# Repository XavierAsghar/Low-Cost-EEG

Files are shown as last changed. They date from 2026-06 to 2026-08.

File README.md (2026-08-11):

# Low-Cost-EEG
As part of my Masters Project at University, I have created my own EEG module, with the goal of reducing the cost of EEG technology, and removing barriers to conducting BCI projects/research. 
The module has been verified through the successful detection of Alpha Waves, SSVEPs, and P300s. Additionally the module can also be used to measure other biopotentials, including EMG and ECG. The component cost of the module is £69.07 for 4-Channels, and £99.92 for 8-Channels.

conc 1

### The Hardware
* Up to 8-channels of electrodes can be connected to the input pin headers.
* Texas Instruments ADS1299 EEG Analogue Front-End amplifies and digitises the EEG signal at up to 500 SPS
* The ESP32-S3 then reads the EEG data, and transmits it to a a host computer using Bluetooth Low Energy
* A python script on the host computer unpacks the EEG data, and pushes it to the Lab-Streaming-Layer, for visualisation and recording
* The module is battery powered to ensure patient safety via electrical isolation
* The built in driven right leg helps to cancel common-mode noise

All testing so far has been conducted with standard gold-cup electrodes. For full details of the design and verification of the module, see the Final Report PDF located in the documentation folder. Additionally for complete instructions to use the module, see the User Guide PDF in the same folder. I reccomend using Brainvision LSL Viewer application to view the recorded EEG data in real-time, or the LabRecorder application to record the EEG data.

This repository contains all of production files necessary to create your own module, as well as the source code, and Altium and Inventor Projects needed to modify/continue development of the project. There are several improvements I would like to make to the project before considering it complete, which are discussed in my final report. I have also included the python scripts I used to test for alpha waves, SSVEPs, P300s, and to perform a concealed information test (lie detector).

This project is licensed under the GPL V3 license

### Safety Warning
When connected to a subject, the device must be battery powered, and the USB-C must be disconnected. This is to ensure electrical isolation of the subject from mains.

alpha test

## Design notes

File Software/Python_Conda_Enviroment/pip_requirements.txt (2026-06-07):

bleak==2.1.1
cffi @ file:///D:/bld/cffi_1761202855497/work
contourpy @ file:///C:/miniconda3/conda-bld/contourpy_1763643943275/work
cycler @ file:///C:/Users/task_176606794786808/croot/cycler_1766068049869/work
fonttools @ file:///C:/miniconda3/conda-bld/fonttools_1765445216921/work
joblib @ file:///C:/Users/task_176786740206630/croot/joblib_1767868144069/work
kiwisolver @ file:///C:/miniconda3/conda-bld/kiwisolver_1764159385651/work
matplotlib==3.10.8
mkl-service==2.5.2
mkl_fft @ file:///C:/miniconda3/conda-bld/mkl_fft_1761592917950/work
mkl_random @ file:///C:/miniconda3/conda-bld/mkl_random_1761593166070/work
numpy @ file:///C:/Users/task_177073259650431/croot/numpy_and_numpy_base_1770732703057/work/dist/numpy-2.4.2-cp312-cp312-win_amd64.whl#sha256=695446e7c6dcc91b4f9b187a8af23d4024c9bd8d6a7398d7e5dc9f70c9d701d3
packaging @ file:///C:/miniconda3/conda-bld/packaging_1761049137378/work
pandas @ file:///C:/Users/task_177324583246542/croot/pandas_1773246097950/work
pillow @ file:///D:/bld/pillow_1726075241382/work
ply @ file:///home/conda/feedstock_root/build_artifacts/ply_1733239724146/work
pycparser @ file:///home/conda/feedstock_root/build_artifacts/bld/rattler-build_pycparser_1733195786/work
pygame @ file:///D:/bld/pygame_1727636579027/work
pylsl==1.18.1
pyparsing @ file:///C:/miniconda3/conda-bld/pyparsing_1763973902692/work
PyQt6==6.7.1
PyQt6_sip @ file:///C:/b/abs_28s7k4h_hl/croot/pyqt-split_1740498234166/work/pyqt_sip
python-dateutil @ file:///C:/b/abs_3au_koqnbs/croot/python-dateutil_1716495777160/work
pyxdf @ file:///home/conda/feedstock_root/build_artifacts/pyxdf_1774461975754/work
scikit-learn @ file:///C:/b/abs_45qemhn4lg/croot/scikit-learn_1753427401078/work
scipy @ file:///C:/Users/task_177325432223808/croot/scipy_1773254468529/work/dist/scipy-1.17.1-cp312-cp312-win_amd64.whl#sha256=9e52a540af6dfab956853adc7e87ea66341768053491750b0e193e4baa18feb1
setuptools==80.10.2
sip @ file:///D:/bld/sip_1759437922648/work
six @ file:///C:/b/abs_149wuyuo1o/croot/six_1744271521515/work
sounddevice @ file:///D:/bld/python-sounddevice_1769251727958/work
threadpoolctl @ file:///C:/miniconda3/conda-bld/threadpoolctl_1764361791480/work
tomli @ file:///home/conda/feedstock_root/build_artifacts/bld/rattler-build_tomli_1774492402/work
tornado @ file:///C:/Users/task_176599264648662/croot/tornado_1765992760941/work
typing_extensions==4.15.0
tzdata @ file:///home/task_176829656558347/croot/python-tzdata_1768296637279/work
wheel==0.46.3
winrt-runtime==3.2.1
winrt-Windows.Devices.Bluetooth==3.2.1
winrt-Windows.Devices.Bluetooth.Advertisement==3.2.1
winrt-Windows.Devices.Bluetooth.GenericAttributeProfile==3.2.1
winrt-Windows.Devices.Enumeration==3.2.1
winrt-Windows.Devices.Radios==3.2.1
winrt-Windows.Foundation==3.2.1
winrt-Windows.Foundation.Collections==3.2.1
winrt-Windows.Storage.Streams==3.2.1

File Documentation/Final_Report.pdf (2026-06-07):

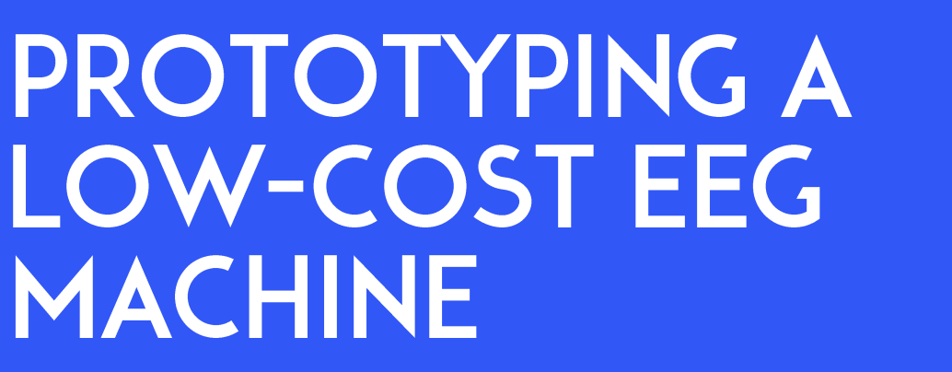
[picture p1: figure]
Prototyping a Low - Cost EEG Machine

Abstract Word Count: 248
Body Word Count: 12,402

Supervisor: Dr Nic Zhang
Assessor: Professor John Taylor

Student Number: 219268967
Integrated Mechanical and Electrical Engineering

Ethical Approval has been Received for this Project

## Xavier Asghar - MEng Final Project Report - 2025/26

Brain-computer interfaces (BCIs) have an expanding range of applications, from assistive technologies for individuals with motor impairments, to autonomous control of mechatronic systems. The increasing availability of commercial EEG devices, from companies such as OpenBCI and Emotiv, has helped make BCI research more accessible outside of clinical and laboratory settings. However these commercial offerings remain prohibitively expensive, often retailing for approximately £1000, and some requiring further subscriptions to access raw data. This high cost has largely excluded EEG technology from educational environments, where it could serve as a platform for student research projects, or as a teaching tool, not just for BCIs, but for signal processing, feature extraction and machine learning.

This report presents the design and validation of a low-cost, open-source EEG module, intended to be easily reproducible. The system utilises the Texas Instruments ADS1299 EEG analogue front end to record high-fidelity EEG signals, alongside an ESP32-S3 microcontroller to wirelessly transmit data to a host computer using Bluetooth Low Energy. A python bridge then pushes the data to the Lab Streaming Layer, enabling real-time visualisation, time-synchronised recording, and integration with established EEG tools. The system records up to 8-channels of 24-bit EEG data at 500 samples per second with no packet loss, and has been validated through the successful detection of alpha waves, SSVEPs, and P300 responses; features that often form the base of BCI systems. With a 4-channel component cost of just £68, the module brings high quality EEG to a cost feasible for educational deployment.

[248 out of a maximum of 250 words]

01 | List of Symbols | 3

# 02 Introduction

| Project Context • Project Aims • Scientific Background | 4
03 | Literature Review Commercial Offerings • Academic Prototypes | 8
04 | System Design Architecture • Firmware • Software • PCB • Mechanical | 10
05 | System Verification EMG • ECG • Alpha Waves • SSVEPs • P300s | 25
06 | Discussions & Conclusions Objectives • Application • Limitations • Improvements • Conclusion | 33
07 | Project Review | 38
08 | Acknowledgements | 40
09 | References | 41
10 | Appendices | 46

# 1. List of Symbols

### 1.1 List of Acronyms

ADC | Analog to Digital Converter
BCI | Brain Computer Interface
BLE | Bluetooth Low Energy
BOM | Bill of Materials
CMRR | Common Mode Rejection Ratio
DRL | Driven Right Leg
ECG | Electrocardiogram
EEG | Electroencephalography
EMG | Electromyography
EMI | Electromagnetic Interference
ENIG | Electroless Nickel Immersion Gold
EP | Evoked Potential
ERP | Event Related Potential
ESD | Electrostatic Discharge
FFT | Fast Fourier Transform
GUI | Graphical User Interface
HASL | Hot Air Solder Levelling
IC | Integrated Circuit
ISR | Interrupt Service Routine
LDO | Low-Dropout Regulator
LSL | Lab Streaming Layer
MUAP | Motor Unit Action Potential
PCB | Printed Circuit Board
RTI | Referred to Input
SNR | Signal to Noise Ratio
SPI | Serial Peripheral Interface
SPS | Samples Per Second
SSVEP | Steady State Visually Evoked Potential
TI | Texas Instruments
VEP | Visually Evoked Potential
XDF | eXtensible Data Format

# 2. Introduction

### 2.1. Project Context

Electroencephalography (EEG) is a non-invasive method of recording spontaneous electrical activity, originating from summed synchronised synaptic activities in populations of cortical neurons in the brain [1, p. 7]. EEG measurements are taken by placing electrodes at multiple locations on the patient’s scalp, and recording the subsequent voltage fluctuations measured at each location. While traditionally used primarily in clinical neurophysiology to monitor and diagnose conditions such as epilepsy, sleep disorders, and brain injuries [2], technological advancements in recent decades have opened up a wide range of new applications involving brain-computer interfaces (BCIs). BCIs use real-time EEG data to control mechanical and electronic devices, with applications including assisting individuals with disabilities and motor impairments, autonomous navigation of mechatronic systems, as well as neurogaming and entertainment [3].

In recent years EEG technology has become more widely available outside of a lab setting, with companies like Emotiv, OpenBCI, Muse, and NeuroSky producing consumer friendly EEG packages that have reduced the barriers to conducting EEG related research [4]. Some of these headsets are shown in Figure 1. However, these devices, which are typically intended to be sold directly to consumers, produce results of varying accuracy, with increased levels of noise [5]. Additionally, a premium is often charged for these devices, as well as for access to proprietary software to view raw EEG data [6], with the more advanced headsets, like OpenBCI’s Ultracortex, or Emotiv’s EPOC X both costing upwards of $1000 [7] [8]. This is in spite of the fact that the core components used to measure biopotentials are not overly expensive, nor are the engineering principles behind these devices overly complex [9].

The high cost of consumer EEG headsets has largely prevented the deployment of EEG technology in educational settings [10] to teach students the fundamentals of brain-computer interfaces. However, by utilising standalone electrodes, rather than relying on fully integrated headset systems, the costs can be brought down to a level feasible for educational deployment. Therefore, this project seeks to develop a low-cost, easily reproducible, and open-source EEG module designed specifically to be used as a teaching tool, as well as for use in future EEG related final year projects.

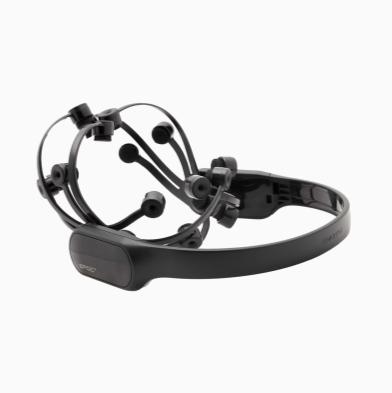
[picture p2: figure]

Figure 1: Commercial EEG offerings, from left to right: OpenBCI Ultracortex [7], Emotiv EPOC X [8], Muse 2 [11]

### 2.2. Project Aims

The primary aim of this project is to use low cost, off the shelf components to design, build, and validate a prototype EEG module. The module must be capable of safely measuring known EEG features, and performing basic data acquisition and signal processing, ensuring the data is easily accessible to the end user. Ultimately the system must be fully documented so it can serve as a reproducible, open-source, educational tool for future brain computer interface research.

It is important to note that several examples of broadly similar low-cost EEG solutions can be found in the literature, as detailed in section 3. However, whilst these papers serve as strong proofs of concept, they fail to provide the reader with sufficient resources to recreate their work, lacking fully realised electrical schematics and code files. The goal of this project is to not just create a tool that can be used within the university, but also can be easily recreated by anyone looking to conduct EEG related research themselves.

To achieve these aims, the project can be broadly divided into four primary objectives, described in Table 1.

Table 1: Project Objectives

Objective 1: Hardware Design and Assembly

Design a low cost printed circuit board (PCB) capable of accurately acquiring EEG measurements from input electrodes, and wirelessly sending the EEG data to an external computer. The PCB must be battery powered, and fully isolated from mains to ensure patient safety.

Objective 2: Software and Firmware Integration

Develop a robust data transmission pipeline, capable of reading data from the analogue front end, wirelessly transmitting said data to a computer, and providing the user with real-time viewing and time-synchronised recording.

Objective 3: System Validation

Test the hardware and software stack to verify its accuracy and safety. This involves conducting human trials to identify known EEG features, including alpha waves, SSVEPs, and P300s

Objective 4: Open-Source Documentation

Produce a comprehensive set of documentation, including a user guide, PCB schematics and Gerber files, commented firmware code and python analysis scripts in order to facilitate future scaling up of the prototype, as well as use and modification in other projects.

### 2.3. Scientific Background

EEG signals are miniscule in magnitude, typically in the order of microvolts [1, p. 26], due to the layers of cerebrospinal fluid, meninges, bone, and skin they must traverse prior to reaching the electrodes on the patient’s scalp [12]. Therefore, recording EEG data necessitates equipment with high levels of precision, as well as adherence to proper procedure when applying the electrodes to a patient. The recorded data originates primarily from the cerebral cortex, the outermost layer of the brain, which contains 14 to 16 billion neurons [13]. This makes the isolation of signals originating from specific neurons impossible, and thus the voltage fluctuation measured at the scalp represents the sum of activities generated from many neural sources surrounding the electrodes [1, p. 8].

Typically, a minimum of three electrodes are required to record EEG data: an active electrode, a reference electrode, and a bias electrode, where the measured voltage is the potential difference between the active, and reference electrode [1, p. 11]. The bias electrode biases the patient such that the common-mode voltage of the active and reference electrode stays within the dynamic range of the EEG circuitry, preventing saturation of the output. More advanced EEG systems also use the bias electrode as part of a noise cancelling feedback loop, called a driven right leg (DRL), where common-mode noise measured from the electrodes, is inverted and fed back into the patient. This helps eliminate the mains-frequency interference that is often present in EEG measurements. [14, p. 68].

The electrodes are most commonly placed on the scalp at some or all of the locations set out by the 10-20 system, shown in Figure 2. This system splits the skull into increments of 10% and 20%, and identifies each location with a letter and number describing the respective brain region and brain side [15]. If using traditional wet electrodes, the skin must be cleaned, and conductive paste must be applied during the electrode application, in order to lower the electrode-skin impedance. On the other hand, dry electrodes can be applied directly to the skin, greatly reducing the required preparation time. However, these electrodes have larger and more unstable electrode-skin impedances, reducing the quality of the recorded data [16].

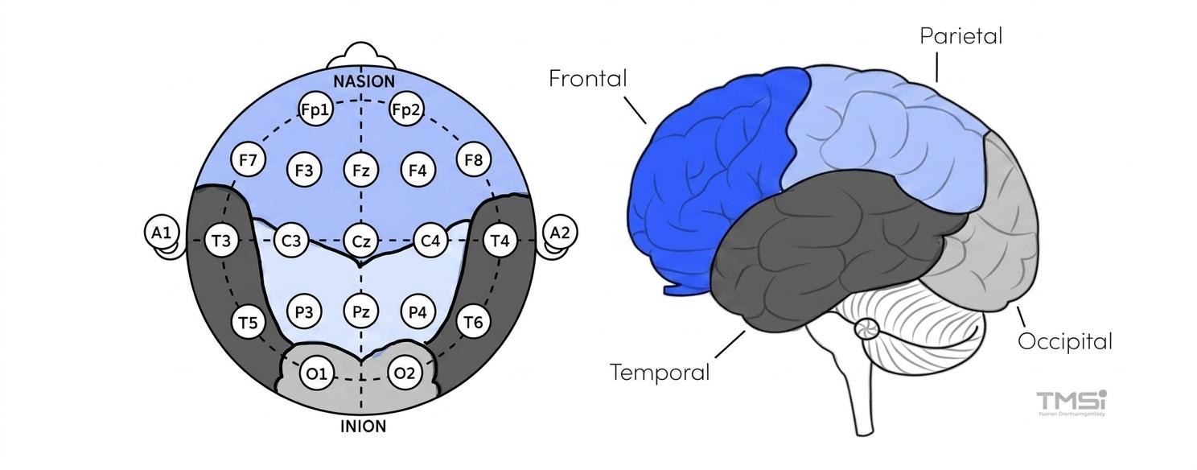
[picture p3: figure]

Figure 2: Diagram showing 10-20 System Electrode Locations [17]

When the electrode input reaches the EEG machine, it is first amplified by an instrumentation amplifier to increase its magnitude and remove common-mode noise. The amplifier should have a common-mode rejection ratio (CMRR) of at least 100 dB to sufficiently remove mains frequency interference [18, p. 1365]. The signal is then bandlimited by an analogue filter, in order to prevent aliasing during the analogue to digital conversion. Finally, an analogue to digital converter (ADC) digitises the EEG signal so it can be processed by a microcontroller [18, p. 977]. EEG headsets typically utilise delta-sigma

ADCs, as their high resolution reduces the need for heavy amplification and filtering, reducing the number of required discrete components [19]. A simple block diagram for an EEG system is shown in Figure 3.

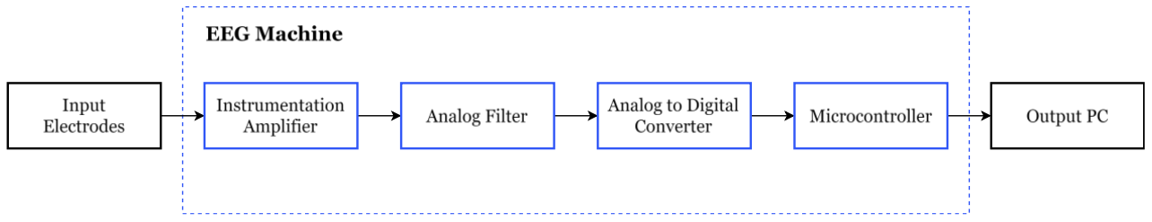
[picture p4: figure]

Figure 3: EEG system block diagram

Once the EEG signal has been digitised by the ADC, it must be transmitted to a computer for signal processing, visualisation, and data analysis. It is important that the data has accurate time synchronisation in order to extract time locked potentials that have been induced by external stimuli. To solve this problem, a framework called The Lab Streaming Layer (LSL) is often used to synchronise data streams from different devices, whilst accounting for network delays, jitters, disconnections and offsets [20]. As well as providing their own software interfaces, companies like OpenBCI and Emotiv both natively support LSL streaming [21], whilst for other platforms, like the Muse, have community created LSL platforms. Once data has been pushed to the Lab Streaming Layer, it can be recorded or visualised by a host of open-source tools, examples of which are given in Appendix I.

EEG machines can be used to record spontaneous EEG activity, as well as event related potentials (ERPs). Spontaneous EEG activity is the background activity of the brain, occurring without any specific external stimulus. It is categorised into frequency bands, each loosely representing different levels of cerebral activity [22]. For example, alpha waves have a frequency of 8 to 13 Hz, and are typically measured from the occipital region of the cortex, from an awake patient with their eyes closed [1, p. 21].

On the other hand, ERPs are time locked EEG responses. These can either be exogenous, commonly referred to as evoked potentials (EPs), which are generated as a result of physical stimulation by a sensory stimulus, or they can be endogenous, being generated by internal cognitive and motor processes [23]. For instance, when a patient observes a light source flickering at a certain frequency, potentials of the same frequency can be measured from the occipital areas of the brain [24]. These are called steady state visually evoked potentials (SSVEPs). On the other hand, possibly the most widely studied endogenous ERP is the P300; a broad positive waveform occurring approximately 300 ms after a patient receives external stimulation [1, p. 62], thought to originate from the brain processing information related to attentional and memory mechanisms [25].

Prior to starting development, a review of existing commercial EEG platforms and relevant academic literature was conducted to gain insight into gaps in the EEG market, to find opportunities for improvement in the current lineup of technology, as well as to inform the design choices made throughout the project.

### 3.1. Commercial EEG Modules

Out of the several commercial EEG headsets on the market, headsets produced by Emotiv have been the most widely used in scientific research [4]. Their EPOC X headset shown in Figure 4.1, provides a highly integrated, user-friendly 14-channel system, albeit with varying levels of reported accuracy [5] [26] [27]. However, its restrictive pricing model limits its ability to be used in an educational environment. The EPOC X is currently priced at $999 [8], while the 32-channel Mind Flex 2 starts at $1,899 [28]. Moreover, accessing and exporting raw EEG data requires a subscription to their EmotivPRO software, costing $149 per month for a standard tier subscription [6].

In comparison, OpenBCI produce a fully open-source EEG platform, which gives the user full control over the entire EEG process. Their Cyton PCB module, shown in Figure 4.2, lets the user choose the number, type and location of electrodes, as well as whether the data is viewed on the OpenBCI GUI, or pushed straight to the Lab Streaming Layer. Whilst providing a platform better suited for research, and of comparable quality to clinical EEG machines [29], the hardware costs remain high. The Cyton board alone costs £933, whilst the complete Ultracortex, which integrates the Cyton board with their own 3D-printed headset and dry-electrodes, costs £2,255 [30].

More recently the Cerelog ESP-EEG board, shown in Figure 4.3, was introduced to the market [31], also with the intention of lowering the cost of BCI technology. Similarly to the OpenBCI Cyton, the Cerelog module is built around the Texas Instruments (TI) ADS1299 [32], which integrates EEG amplification, analogue to digital conversion, as well as other EEG specific features, to provide a fully integrated EEG analogue front end [14]. The Cerelog platform also has strong software integration, allowing the user to view their data on a fork of the OpenBCI GUI, or use the popular Brainflow EEG library to access raw EEG data. However, the system does not yet support wireless data transfer, relying instead on a USB connection. As well as restricting patient mobility, this presents a danger to the user if the host computer is connected to mains, as there will be no electrical isolation of the patient. Furthermore, the hardware remains relatively expensive, with a base price of $650.

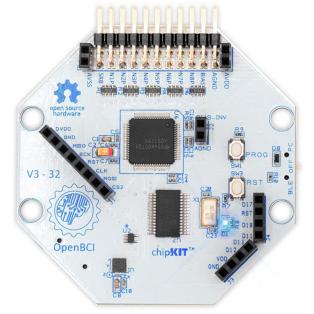
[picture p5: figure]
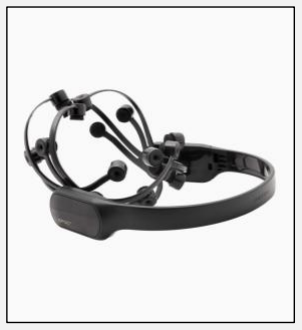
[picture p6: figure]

Figure 4: From left to right: Emotiv EPOC X [8], OpenBCI Cyton [33], Cerelog ESP-EEG [31]

### 3.2. Academic Low-Cost Prototypes

As well as commercial offerings, there are also several studies that document the production of low-cost EEG platforms.

In 2013, Pennsylvania State University researchers also identified a need for low-cost EEG modules to use as an educational tool [9]. They observed difficulties in getting student buy-in for their BCI classes, as the high hardware cost meant students had limited access to EEG equipment. An older, electrocardiogram (ECG) specific version of the aforementioned TI chip; the ADS1298, was paired with a TI MSP430 series
microcontroller, known for its exceptionally low power
consumption [34], to create an EEG acquisition module
with a component cost of under $100, shown in Figure
5. They then validated their system through the detection of alpha waves and a visually evoked p300 response. Overall, a strong EEG platform has been presented, with minor improvements being wireless
data transfer, battery power, and stronger software
integration.

In 2017 Nguyen et al. [35] documented an ADS1299 based EEG system, this time using an STM32F4 microcontroller, which they validated using alpha wave detection and Electrooculography (EOG) eye tracking tasks. To overcome the mobility limitations of previous wired systems, Bluetooth data transmission was implemented using a HC – 05 Bluetooth module. However the authors admit the system was susceptible to high levels of noise, possibly due to not utilising the ADS1299’s driven right leg functionality, highlighting the importance of using the patient bias as an active ground to cancel common mode noise.

More recently, Gao (2023) [36] developed another ADS1299 STM32 EEG system, with the intent of creating an EEG module possessing the accuracy of large laboratory EEG setups, but on a much smaller scale. Once again a separate
bluetooth module, the NRF52832, was used to send
data to a computer. The system, shown in Figure 6, was
verified by using fourier analysis to test for SSVEPs across multiple stimulus frequencies. This paper goes further than the previous examples in documenting their work, with snapshots of electrical schematics, however it is still far from being easily reproducible. Additionally the system is not integrated with any
established EEG software frameworks, like brainflow or
LSL.

In conclusion, the ADS1299 has established itself as the analog front end of choice in low-cost, portable EEG modules, both in commercial products and in academic research. Additionally, alpha wave, P300, and SSVEP detection methods have repeatedly been used as methods of verifying the accuracy of proposed systems. Overall strong proofs of concept for small scale, low cost ADS1299 based EEG systems have been provided. However, the work done in these papers is not easily reproducible, and despite the decreasing costs of EEG hardware, users and researchers are still left without a truly low-cost solution.

Figure 6: Gao (2023) EEG Module

Figure 5: Pennsylvania State University EEG Module

# 4. System Design

### 4.1. Component Selection & System Architecture

4.1.1. ADC Selection

The first stage of the design process involved selecting a suitable analogue to digital converter, as this component dictates the overall system architecture.

As evidenced by the literature review, the ADS1299 is the standard for low-cost EEG modules. This is primarily due to its exceptionally low input referred noise, high CMRR, and large input impedance [14]. The ADS1299 also comes equipped with several EEG specific features, including lead-off detection to identify poor electrode-skin contact, built in driven right leg circuitry for common mode noise cancelation, and an internal multiplexer which allows for the routing of the reference electrode to the negative pin of each differential input. However, this high level of integration carries a financial premium, as the ADS1299 currently retails for £64.57 from Mouser Electronics. To adhere to the low-cost objective of the project, cheaper alternatives were evaluated.

One alternative approach is to use an ECG analogue front end, similarly to how the ADS1298 was utilised at Pennsylvania University. However, since these ICs are intended for ECG applications, where signal amplitudes are orders of magnitude larger [37], they offer comparatively poor noise performance. Another option is to use a non-application specific ADC, such as the Analog Devices AD7779, that also features 8 simultaneously sampled 24-bit channels.

Table 2 compares the performance metrics of these ADCs, specifically evaluating their theoretical capability to measure a 10 µVpp P300 ERP [38]. Referred to input (RTI) noise levels are assuming a maximum PGA gain and minimum data rate, and thus represent a lower bound. The RTI least significant bit (LSB) size has been calculated with Equation 1:

LSBRTI =

2 ∙ (

Vref
PGA Gain)

2

Bits | (Equation 1)

Table 2: ADC performance comparison when measuring a 10 µVpp P300 [14], [39], [40], [41]

IC | RTI Noise (µVpp) | P300 Noise Contamination (%) | PGA Gain | RTI LSB (µV) | P300 Quantisation Steps | Mouser Cost
ADS1299 | 0.98 | 9.8 | 24 | 0.022 | 447.39 | £64.57
ADS1298 | 2.7 | 27 | 12 | 0.040 | 251.66 | £34.39
AD7779 | 2.28 | 22.8 | 8 | 0.037 | 268.44 | £14.49
AD8422* | 0.15 | 1.5 | | | | £5.60
*Note: The AD8422 is an instrumentation amplifier, not an ADC.

The ADS1299 has the lowest RTI noise, as well as the lowest RTI LSB size, enabling precise and low noise acquisition of a P300 wave. In contrast, using the ADS1298 or AD7779 would result in a P300 signal that is contaminated with approximately 25% noise, and recorded at almost half the effective resolution.

The lower performance metrics of the cheaper ADCs could be compensated for by placing an instrumentation amplifier stage prior to the ADC, for instance the AD8422, which has an ultra-low RTI noise of 0.15 µVpp. However, despite outperforming the ADS1299 in terms of noise performance, this would add increased complexity and cost, since each channel would require a dedicated instrumentation amplifier.

Consequently, the ADS1299 was selected. Its low RTI noise and high PGA gain ensure high fidelity signal acquisition, while its EEG specific features minimise circuit complexity and reduce the need for other components. Moreover, in some cases the increased cost can be mitigated by using the 6-channel, or 4-channel variants, which are priced at £51.52 and £32.75 respectively.

4.1.2. Microcontroller Selection

Following the selection of the analogue front end, a suitable microcontroller was required to manage SPI (Serial Peripheral Interface) communication with the ADS1299, and send the EEG data to a host computer.

Project Objective 2 states that data transmission from the EEG module to a host computer must be completely wireless. This is primarily to ensure electrical isolation between the user and mains power; however, it also removes the physical tether to the host device, granting the user full mobility. Consequently, the search was restricted to microcontrollers with Bluetooth integration. Utilising an external Bluetooth module would add unnecessary complexity to the project by way of introducing another serial bridge to the data path, not to mention increasing the bill of materials (BOM), and consuming additional PCB real estate.

This primary constraint was used to narrow down the field to three primary candidates, summarised in Table 3. The STM32 architecture was considered due to its high performance, low power consumption and robust ecosystem [42]. While the STM32F4 range of microcontrollers used by Nguyen et al. [35] and Gao [36] do not come with Bluetooth, STMicroelectronics have a capable dual core Bluetooth offering in the STM32WB55. Alternatively, one of the most widely used microcontrollers for Bluetooth Low Energy (BLE) applications is the Nordic Semiconductor nRF52840, due to its low power consumption and an extremely stable Bluetooth stack. In fact Nordic sells approximately 40% of all BLE chips in industry [43].

Table 3: Bluetooth microcontroller comparison

Micro | Cores | Clock Speed | Max RAM | Max Flash | Unit Cost
STM32WB55 | 1x ARM Cortex-M4 1x ARM Cortex-M0+ | Core 1: 64 MHz Core 2: 32 MHz | 256 KB | 1 MB | £6.77
nRF52840 | ARM Cortex-M4 | 64 MHz | 256 KB | 1 MB | £4.85
ESP32-S3 | 2x Xtensa LX7 | 240 MHz | 512 KB | 16 MB (external) | £1.39

Despite the popular STMicroelectronics and Nordic offerings, the Espressif ESP32-S3 was chosen for this project. As evidenced by Table 3, the ESP32-S3 outperforms the STM32WB55 and nRF52840 in terms of computational power, possessing two 240 MHz cores, and double the amount of SRAM. This dual core architecture allows for data reading, and data sending to each be localised to an individual core, in a way that would not be possible on the nRF52840.

From a hardware design perspective, the ESP32-S3 is widely available as a pre-certified, shielded module: the ESP32-S3-Wroom-1, containing an integrated PCB antenna, crystal, and external flash memory. This, combined with native USB support, once again removes unnecessary complexity from the project, for example RF layout and USB to UART conversion. Additionally, the module form factor is priced very reasonably, with costs starting at £3.80, and development boards costing around £10.

4.1.3. Electrode Selection

While the EEG module is intended to be electrode agnostic, a set of electrodes needed to be selected for system validation. Electrodes generally differ across two primary metrics: active vs passive, and wet vs dry.

Active electrodes, shown in Figure 7.1, amplify the EEG signal directly at the electrode, preventing undesired electrical noise, particularly at mains frequency, from coupling into the lead wires and contaminating the signal. These would require dedicated power routed from the PCB, and are typically more expensive, and more difficult to source than their passive counterparts, that simply transmit the signal to the EEG machine for amplification. Furthermore, research indicates that in high quality, laboratory conditions, specifically with low electrode-skin impedances, passive electrodes provided a cleaner baseline signal [44].

Figure 7: EEG electrode types: active electrodes (left) [45], dry electrodes (middle) [46], and passive gold cup electrodes (right) [47].

Regarding electrode application, wet electrodes are the clinical standard. These require the use of a conductive paste, gel or saline solution during the application process, which will dry out after a certain amount of time. Moreover, the skin needs to be prepared before application to reduce the electrode skin impedance, typically by applying an abrasive gel like Nuprep or using alcohol wipes and mechanical abrasion. On the other hand, dry electrodes, as shown in Figure 7.2, can be applied directly to the scalp without the need for preparation. While convenient, this comes at a cost to performance, as they were found to produce significantly larger noise levels compared to both active and passive wet electrodes when conducting a P300 oddball test [48].

For this project, passive wet gold cup electrodes were chosen, primarily due to their low cost, wide availability, and reliable signal acquisition. While the ease of use of dry electrodes is well suited to an educational environment, establishing clean EEG data was prioritised for the initial hardware tests. However, in the future it may be worthwhile testing the system with dry electrodes, to assess their viability. A total of eight electrodes were sourced from Chinese app Pinduoduo, amounting to £15.

4.1.4. Overall System Architecture

Following the selection of the primary hardware components, a complete system architecture was defined. Figure 8 illustrates this architecture, mapping out the signal flow from the brain to the final GUI.

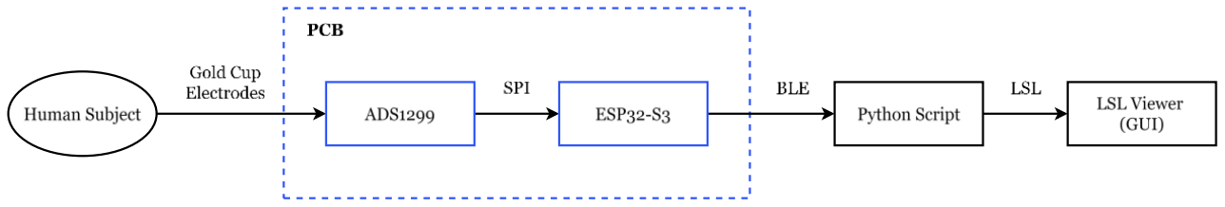
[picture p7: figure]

Figure 8: System architecture flow chart

EEG data is first acquired from the scalp using gold cup electrodes. This necessitates skin preparation as well as the use of conductive paste during the application process. The ADS1299 then amplifies the signal, removing common mode noise, before digitising the data from a maximum of 8 channels.

The digitised data is subsequently transmitted via SPI to the ESP32-S3 microcontroller, where it is batched into packets to be transmitted using the BLE protocol, with the ESP32-S3 acting as a GATT (Generic ATTribute Profile) server. This ensures that electrical isolation is maintained between the user and mains.

Finally, at the host computer, a python script will act as the GATT client, subscribing to notifications from the GATT server. The script unpacks the incoming byte arrays, including checking for lost packets, before pushing the data to an LSL outlet. Utilising the LSL framework allows the data to be viewed in real time using tools such as BrainVision LSL Viewer or OpenViBE, and recorded using Lab Recorder. Additionally, it allows users to synchronise the recorded data with external stimuli, through the use of LSL marker streams.

### 4.2. Bench Prototyping and Firmware Design

4.2.1. Initial Prototyping

Once component selection had been completed, the development boards for the ADS1299 (ADS1299EEGFE-PDK) and ESP32-S3-Wroom-1 (S3-DevKitC-1) were purchased to conduct initial tests.

To establish a performance baseline prior to introducing custom firmware, the ADS1299 was first evaluated using the included MMB0 motherboard. This board interfaces between the ADS1299 and the Texas Instruments evaluation software, allowing for visualisation and Fast Fourier Transform of channel inputs, and direct manipulation of the internal control registers.

Initial validation was conducted by connecting the positive channel and reference inputs of the development board to a signal generator. Figure 9.1 shows the results of a 1 mVpp input sine wave, while Figure 9.2 shows the respective frequency domain FFT. Further validation was performed by routing the ADS1299’s internally generated 3.6 mVpp test signal to channel 1, the results of which are shown in Figure 9.3.

Figure 9: ADS1299 EVM tests: 1 mVpp input (left), 1 mVpp FFT (middle), internally generated square wave (right)

Further bench tests verified the DRL circuitry, PGA configuration and bipolar supply operation. In addition, the intrinsic noise floor was recorded at 2 µVpp, confirming the device was operating as set out in the datasheet.

This initial testing phase was useful for understanding functionality and register setup of the ADS1299. Once completed, the analogue front-end board was separated from the MMB0 motherboard, and jumper wired to the S3-DevKitC-1, as shown in Figure 10. Table 4 lists the wire connections between the two boards.

Table 4: ADS1299 ESP32 communication pins

ESP32 Pin | ADS1299 Pin
8 | RESET
9 | DRDY
10 | CS
11 | DIN (MOSI)
12 | SCK
13 | DOUT (MISO)
18 | START

Figure 10: Development Setup

4.2.2. ADS1299 Communication Library

The next stage of development involved the creation of a library to interface the ESP32-S3 with the ADS1299, which communicates using SPI. Aside from the four main SPI pins; DIN, DOUT, SCK, and CS, the ADS1299 also has several dedicated communication pins including RESET, START, PWDN and DRDY.

During standard operation the ADS1299 is placed in the Read Data Continuous (RDATAC) mode. When the START pin is low, and on the falling edge of the DRDY pin, DOUT releases 216 bits of data, comprising of 24 status bits, followed by eight 24-bit channel readings. In order to configure the device, including reading from and writing to internal registers, the data stream must be halted using the Stop Read Data Continuous Command (SDATAC), releasing the SPI buses.

An open-source communication library for the ADS1299 already existed, having been developed by Conor Russomanno, one of the founders of OpenBCI [49]. However, this library was specifically designed for 8-bit AVR microcontrollers, for instance the ATmega328P found on the Arduino Uno R3, as it manipulates the AVR specific SPI control registers directly. This renders the library incompatible with the 32-bit Xtensa processors found on the ESP32-S3. Furthermore, the original library was designed to act as a pass through, printing all received data straight to the serial port to be processed by a host PC, while the architecture used in this project transmits data over Bluetooth instead.

To resolve these incompatibilities, Russomanno’s library was modified to use the standard Arduino SPI library, making it compatible with any microcontroller using the Arduino framework. Additionally, the following changes were implemented:

1. Rather than pushing recorded bits straight to the serial monitor, they are sign extended into 32-bit integer longs, and which are then returned as outputs.
2. The updateData function responsible for reading data from the ADS1299 was changed with the intention of being called by an interrupt when the DRDY pin has been pulled low, rather than being polled from the main loop.
3. A new updateDataPacket function was added, which skips sign extension and reading the data into a long, instead dropping the channel data directly into a byte array, to be sent over Bluetooth.
4. Correct power up sequencing was added to the setup function, removing the need for the user to manually follow the power-up sequence set out by the datasheet before sending instructions.

The complete source code for the revised ADS1299 communication library can be found in Appendix B.

4.2.3. ESP32-S3 Firmware

With the ADS1299 communication library complete, the ESP32-S3 firmware was developed with Platformio, using the Espressif’s Arduino Core. The firmware has two primary objectives: to accurately read data from the ADS1299 on the falling edge of the DRDY pin, and to transmit data to the host computer using Bluetooth Low Energy, with high-throughput and no data loss. Combining these two objectives onto a single execution thread risks one task blocking the other, particularly due to the precise timing requirements of each task. Even at the lowest data rate, the ADS1299 is sending a 216-bit sample every 4 milliseconds, that needs to be read, decoded, packaged and transmitted. To solve this problem, the dual core architecture of the ESP32-S3 was utilised, with one core in charge of reading data, and the other responsible for transmitting it. The overall structure of the firmware can be seen in Figure 11.

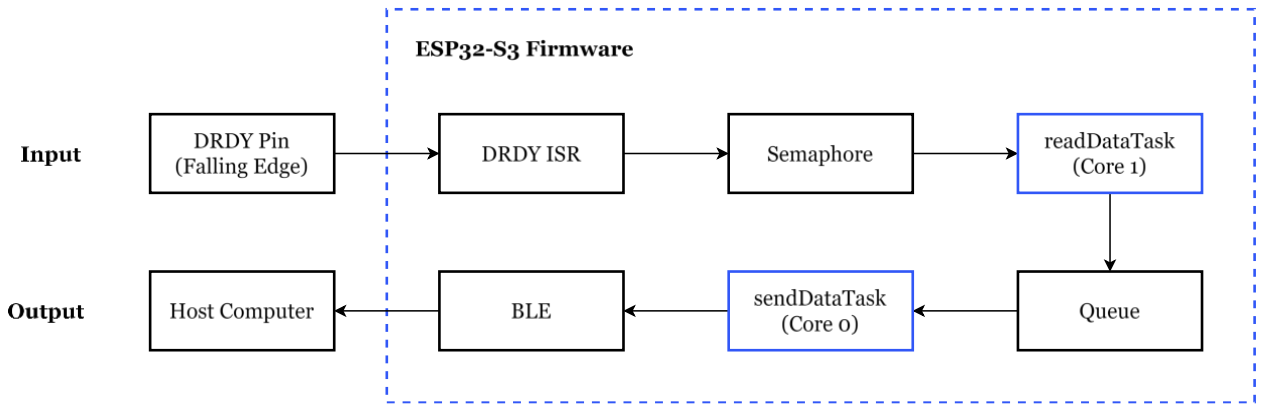
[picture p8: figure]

Figure 11: ESP32-S3 firmware architecture diagram, showing dual core pipeline.

When the DRDY pin is pulled low, indicating that there is a new sample available, an interrupt service routine (ISR) is called, which gives to a binary semaphore, and immediately yields to a higher priority task, if one is waiting. The ISR, shown in Listing 1, has been kept minimal, to ensure that other DRDY interrupts are not delayed, reducing the risk of sample loss.

Listing 1: DRDY ISR function

void IRAM_ATTR dataReadyISR() {
BaseType_t xHigherPriorityTaskWoken = pdFALSE; xSemaphoreGiveFromISR(drdySemaphore, &xHigherPriorityTaskWoken); if (xHigherPriorityTaskWoken) {
portYIELD_FROM_ISR();
}
}

The task of reading data from the ADS1299 is pinned to core 1 of the ESP32-S3, at a priority level of 3. This task, shown in Listing 2, spends most of its time blocked, waiting for the semaphore to be released. When the semaphore is given by the ISR, the task wakes up and increments a sample counter, which is put in byte 0 of a 28-byte packet. The updateDataPacket function is then called to fill the remaining 27 bytes with EEG data read from the ADS1299, and the completed packet is pushed to a queue, to be sent to the secondary task running on the other core. The sample counter can be used by the host to determine if any samples have been lost.

Listing 2: Read data task (core 1)

for(;;) {

if (xSemaphoreTake(drdySemaphore, portMAX_DELAY) == pdTRUE) {
dataPacket[0] = sampleCounter++; | // 1. Assign the Sample Counter
ADS.updateDataPacket(dataPacket); | // 2. Read the SPI Data
xQueueSend(packetQueue, dataPacket, 0); // 3. Send to the Bluetooth Core }
}

The task of sending data to the host computer runs on Core 0 at a priority level of 1, alongside the BLE stack, and is shown in Listing 3. This core is blocked until a sample becomes available in the queue, at which point it is added to a 224-byte batch buffer. Once eight packets have been received, and the buffer is full, the batch is transmitted as a single GATT notification. Batching the data is necessary as BLE notifications carry overheads, and thus sending each 28-byte sample individually would consume a greater amount of radio time. In particular a factor of 8 was chosen as it fits nicely within BLE’s 251-byte extended data channel payload [50], maximising the data sent with each notification.

Listing 3: Send data task (core 0)

// Wait for a single 28-byte packet from Core 1
if (xQueueReceive(packetQueue, &singlePacket, portMAX_DELAY) == pdPASS) { // Copy the 28 bytes the 224-byte batch buffer memcpy(&batchBuffer[batchCount * 28], singlePacket, 28);
batchCount++;
// After 8 packets, send the full 224-byte batch
if (batchCount == 8) {
pCharacteristic->setValue(batchBuffer, 224); pCharacteristic->notify();
batchCount = 0; // Reset the batch count
}
}

The sample queue has a depth of 256, providing approximately half a second of buffering when the ADS1299 is running at 500 SPS, absorbing any short term BLE delays. The system is capable of transmitting data at 500 SPS with no data loss (equivalent to 14 kB/s), however at 1000 SPS packets start to be dropped due to limitations regarding the windows connection interval. A possible mitigation would have been to use Bluetooth Classic rather than BLE, which provides a continuous steam of data, but is only supported on the original ESP32, and not the newer ESP32-S3 selected for this project. Nevertheless, 500 SPS, which results in a Nyquist frequency of 250 Hz, is more than enough for most EEG applications, where the data is often filtered to cutoff frequencies far below this value.

The code is also written such that there is an initial connection phase, where the ADS1299’s DC lead off circuitry is active. This is where a small excitation current is injected to each of the active electrodes, and a comparator threshold detects whether the resulting voltage indicates an open circuit. Once the connections are verified, the user can press the boot button to disable the lead-off circuitry, which would have otherwise contaminated the EEG measurements.

The completed firmware uses 900 KB of flash, and 140 KB of internal SRAM, leaving 7.1 MB and 248 KB respectively free for future development. The complete source code for the ESP32-S3 can be found in Appendix C.

### 4.3. Host Software Design

4.3.1. Python BLE Client and LSL Bridge

The host software is responsible for receiving and decoding the EEG data stream sent by the ESP32-S3, before pushing the data to the Lab Streaming Layer for visualisation and recording. Python was chosen as the implementation language due to the availability of mature libraries for relevant tasks: Bleak for receiving BLE data, Pylsl for pushing data to the LSL, and Asyncio to run and manage an event loop.

Python’s Asyncio framework was used to manage the operation of the host script. Asyncio implements cooperative concurrency on a single thread, which is controlled by a central event loop, scheduling tasks that voluntarily yield control at explicit ‘await’ points. Unlike multi-threading, this model guarantees that no task is interrupted mid execution, eliminating the need for locking of variables to prevent race conditions. The Bleak library by default runs on top of Asyncio, as BLE communications are inherently I/O bound, and the system needs to be able to read the notification data without blocking other sections of the code. The script is organised into three concurrent tasks running on the event loop, and the overall structure can be seen in Figure 12.

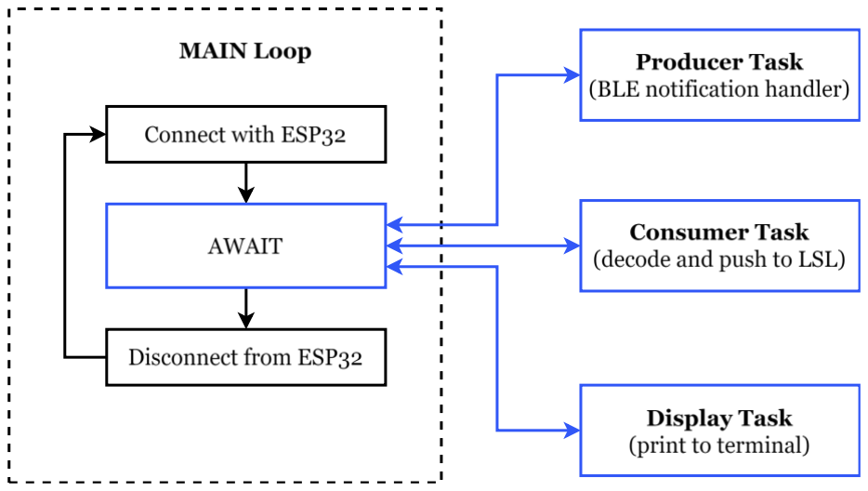
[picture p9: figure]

Figure 12: Python script structure diagram

The producer task is the notification handler, that when a BLE notification arrives, performs a single length check, before depositing the 224-byte batch into a queue. Similarly to the DRDY ISR, the notification handler returns as quickly as possible to avoid blocking subsequent data packets.

The consumer task awaits batches from the queue, unpacking each 224-byte batch into its eight constituent ADS1299 samples. The first byte of each sample contains the sample counter assigned by the ESP32-S3 (Listing 2), bytes 1-3 contain the ADS1299 status bits, including the results of lead-off detection, while the remaining 24 bytes contain the eight channel readings. Upon dividing the batch, drop detection is performed by tracking the expected next sample counter. If the counter has advanced by more than one, a counter tracking the number of dropped samples is incremented, and a NaN filled sample is pushed to the LSL, in order to maintain temporal alignment. This process is shown in Listing 4.

Listing 4: Consumer task drop detection

if state.expected_counter is not None:
dropped = (sample_counter - state.expected_counter) % 256
if dropped > 0:
state.drop_counter += dropped
# Push what we have so far, then insert NaNs, then continue if chunk:

outlet.push_chunk(chunk)
chunk = []
nan_sample = [math.nan] * 8 outlet.push_chunk([nan_sample] * dropped) state.expected_counter = (sample_counter + 1) % 256 ...

The consumer task then decodes the data for each channel, by reassembling its three constituent bytes into a 24-bit unsigned integer, sign extending to 32-bits, and multiplying by the scale factor shown in Equation 2 to obtain the channel reading in microvolts. Decoded samples are accumulated into a chunk before being pushed to the LSL outlet, reducing the number of times the push_chunk() function has to be called.

Vcℎ = raw ∙

2 ∙ Vref
Gain ∙ 2

24 (Equation 2)

A final display task runs every 100 ms, printing the most recently received sample, the dropped samples counter, the current queue depth, and the lead-off status bits, allowing the user to verify that data is flowing correctly, without having to launch a separate viewer. Rather than reading from the queue directly, the task reads from a shared state that was populated by the consumer task.

The main event loop is responsible for device discovery, and connection and reconnection. On startup, the script scans for an advertising peripheral with device name: ESP32_EEG_DATA, and then subscribes to its notifications. If the disconnection event is triggered by Bleak’s disconnection callback, the loop resets and begins scanning for the ESP32 again. On the other hand, if the stop event is triggered by the user pressing CTRL+C, the loop is terminated, and the program ends.

The complete source code for the host script can be found in Appendix D. This code was packaged into a 12 MB executable file using PyInstaller.

### 4.4. PCB Design

4.4.1. Electrical Schematic

With the firmware and host software validated using the ADS1299 evaluation module and ESP32-S3 devkit, the next stage of development was to integrate the prototype into a single PCB. The principal goal when designing the PCB was keeping noise and potential interference around the ADS1299 to a minimum to guarantee high quality EEG measurements. The PCB also needs to be battery powered, in order to maintain electrical isolation, as well as being able to be connected to a computer for flashing. The schematic and layout were developed using Altium Designer, and the OpenBCI Cyton schematic [51] was used as a reference for some of the analogue front end circuitry. The complete schematic can be viewed in Appendix E.

Most EEG electrode sets come with touchproof (DIN 42802) connectors, as these are the standard for connecting to clinical EEG machines. However sourcing PCB mount, touchproof connector receptacles proved a challenge, as these are components typically only sold to suppliers of medical equipment. Therefore standard 2.54 mm pin headers were used as the electrode inputs, due to the fact that some electrode sets can be bought with Dupont style terminations. Alternatively, the touchproof connectors can quite easily be removed and replaced by soldering female Dupont wires, which is the method that was used for this project.

The electrode inputs are then routed to bi-directional ESD protection diodes, that prevent voltage spikes originating from the body from damaging the ADS1299. Additionally, the electrode inputs pass through an RC low-pass filter before reaching the ADS1299 channel inputs. This is primarily to attenuate modulation frequency noise (1.024 MHz), as the digital decimation filter inside the ADS1299 has unity gain at multiples of fMOD, and thus any noise at these frequencies is passed straight to the ADC inputs. The filter is comprised of a 2.2 kΩ resistor, and a 1 nF capacitor, resulting in -23 dB gain at 1.024 MHz. Class 1 capacitors were used here rather than the standard Class 2 for their improved overall stability, with C0G having a ±0.3% capacitance change across its operating temperature, compared to ±15% for X7R [52]. Class 2 capacitors also exhibit piezoelectric behaviour that can create electrical noise [53].

It was chosen to operate the ADS1299 in bipolar supply mode, so that the electrode inputs are naturally centred around 0V, rather than 2.5V. Table 5 shows the required supply rails for the PCB.

Table 5: PCB supply rail characteristics

Device | Supply Rail | Supply Voltage | Typical Current | Peak Current
ADS1299 | AVDD | 2.5V | 7.14 mA
| AVSS | -2.5V | - 7.14 mA
| DVDD | 3.3V | 1 mA
ESP32-S3 | DVDD | 3.3V | | 202 mA

A 3.7V, 2000 mAH LiPo battery was chosen to power the PCB, as the nominal voltage can be easily stepped down to 3.3V, using a low noise, low-dropout regulator (LDO), with an efficiency of 89%. This is ideal, as using switch mode power supplies would introduce voltage ripple and electromagnetic interference (EMI) [54], which could contaminate the EEG signals. Furthermore, assuming a total current draw of 216.28 mA, and approximately 80% overall efficiency, the battery should be able to power the system for a minimum of 7.40 hours.

Figure 13 shows the PCB power supply schematic. AVDD and AVSS for the ADS1299 were generated using a single integrated charge pump LDO, the LM27762, specifically designed for low noise applications. Meanwhile the 3.3V digital supplies for the ADS1299 and the ESP32-S3 were generated with separate low noise LDOs, in order to prevent load induced output droop and voltage ripple caused by the ESP32 from coupling into the ADS1299.

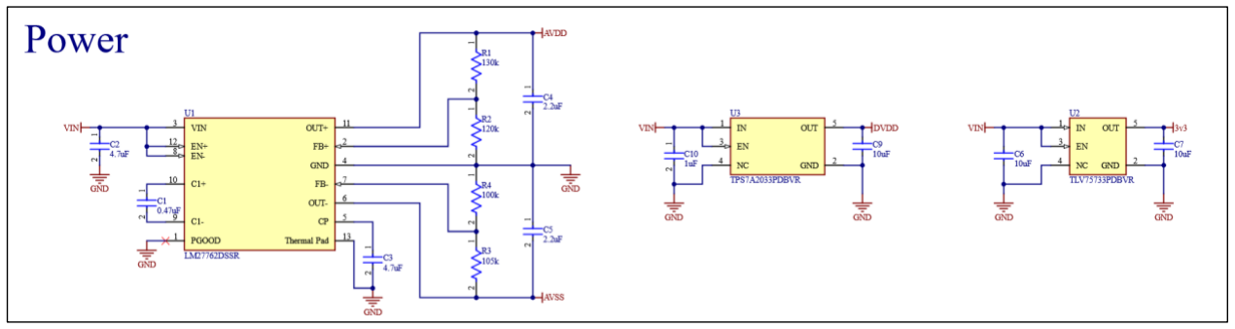
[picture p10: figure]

Figure 13: PCB power supply schematic

The ADS1299 and ESP32 schematics were created adhering as closely as possible to the datasheet recommendations, and following the examples set out by their respective development boards. The ESP32 is flashed using its native USB, and reset and boot buttons have been included in the schematic to allow the ESP32 to be put into programming mode. A SPDT switch on the board allows the user to select either USB 5V, or the LiPo battery 3.7V to be used as the input power source, which can also act as an on-off switch when the USB is not connected. ESD protection diodes have been placed on the USB input, as well as connected to the input battery JST-PH, as these are components that will be touched frequently.

Finally, UART GPIO pins of the ESP32 have been broken out onto pin headers, to act as a failsafe in case the USB communication were to fail, and also to be used as spare GPIO, for instance if the user wishes to control an external stimulus using the ESP32. Test points have also been placed on the board for each of the supply rails, to facilitate easy troubleshooting in the event of a problem.

4.4.2. PCB Layout

Once again, when laying out the PCB, layout recommendations from component datasheets were adhered to as closely as possible. A four layer; signal, ground, power, signal stackup was used to simplify routing, but most importantly to reduce potential noise. Using a ground plane means that all signals have low-impedance return paths, keeping current loop areas small and reducing cross talk. Furthermore, a ground plane can act as a Faraday cage, absorbing interference from nearby circuits, resulting in stronger signal integrity [55].

The ADS1299 datasheet recommends partitioning the board into analogue and digital sections, as is standard in mixed signal design, in order to prevent digital noise coupling into analogue signals. This approach negates the need for a split ground plane, as digital return currents will remain under the digital signal traces [56, p. 663]. Figure 14 shows the placement of the analogue electrode inputs and ADS1299 on the left side of the board, while the digital ESP32-S3 and power generation circuitry has been placed on the right. Components have been placed predominantly on the top layer for ease of assembly, and the ESP32-S3 antenna has been hung off the edge of the board, to ensure proper clearance.

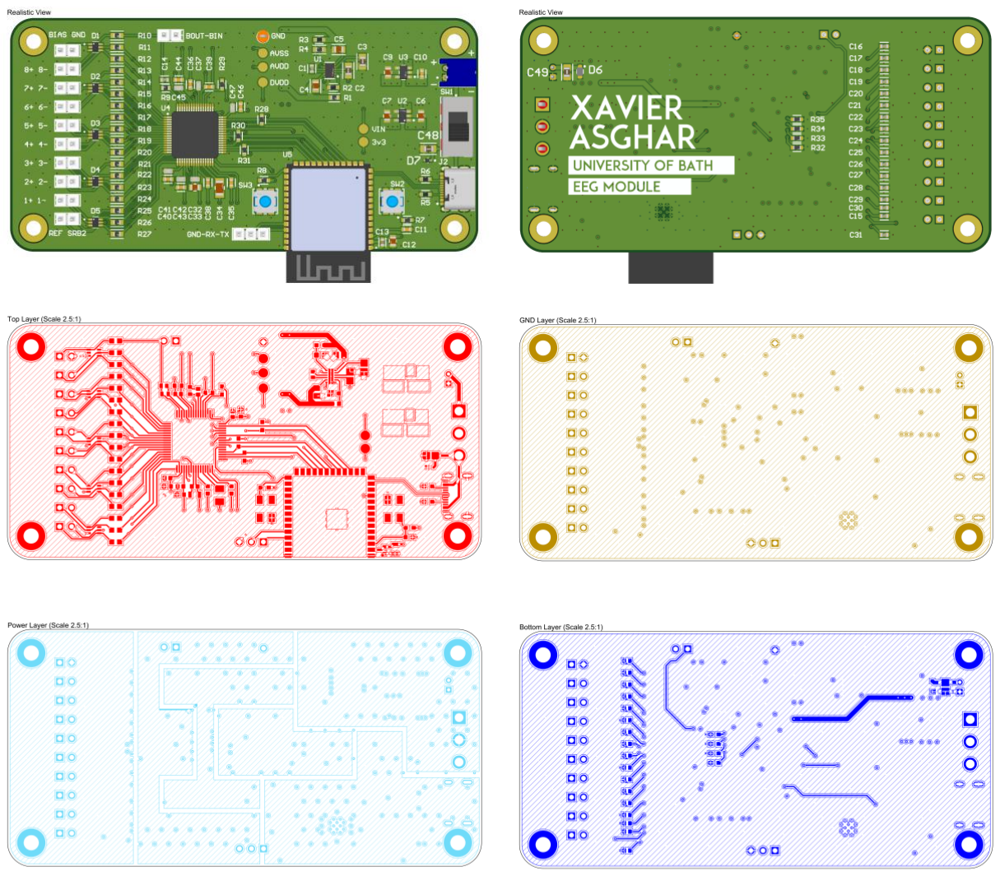
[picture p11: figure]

Figure 14: Complete PCB design: top realistic view (upper-left), bottom realistic view (upper-right), top layer (middle-left), ground layer (middle-right), power layer (lower-left), bottom layer (lower-right).

A segmented power plane has been used to distribute the different supply rails across the board and limit interference from digital rails to the analogue section. Care has been taken not to route signals beneath power plane splits, ensuring all traces have continuous return paths. As per the ADS1299 datasheet, void areas on signal layers have been flooded with ground and stitched with vias to the ground plane, and decoupling capacitors have been placed as close as possible to their respective power pins.

Five boards and one stencil were purchased from JLCPCB for a total of £18.95, including customs duties and tax, but excluding shipping. The boards were ordered with an ENIG (Electroless Nickel Immersion Gold) surface finish instead of HASL (Hot Air Solder Levelling) to guarantee a completely flat surface, which is important for fine pitch SMD components. Additionally, unlike HASL, ENIG finishes are resistant to corrosion and oxidation [57]. The unassembled PCB can be seen in Figure 15.1.

The PCB components were ordered from Mouser Electronics, coming to a total component cost of £99.92, which is already an order of magnitude cheaper than the OpenBCI Cyton board. The cost can be lowered to only £68.07 by substituting the 8-channel ADS1299 with its 4-channel equivalent, the ADS1299-4. With the intended use in a primarily educational environment, 4 channels are more than sufficient to detect a range of EEG features, as is detailed in Chapter 5. The full bill of materials (BOM) can be found in Appendix F.

The board was subsequently assembled, with the top layer components being attached using solder paste and a reflow oven, while the bottom mounted and through hole components were soldered by hand. The assembled PCB can be seen in Figure 15.2.

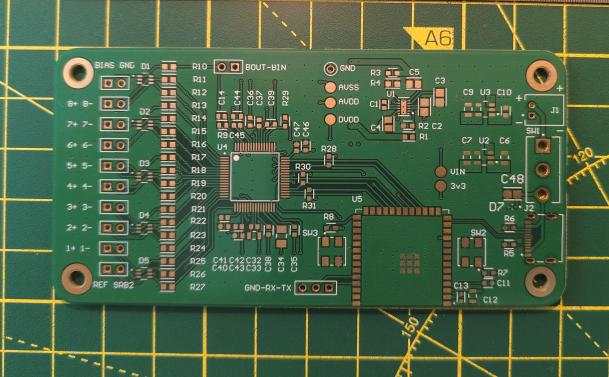
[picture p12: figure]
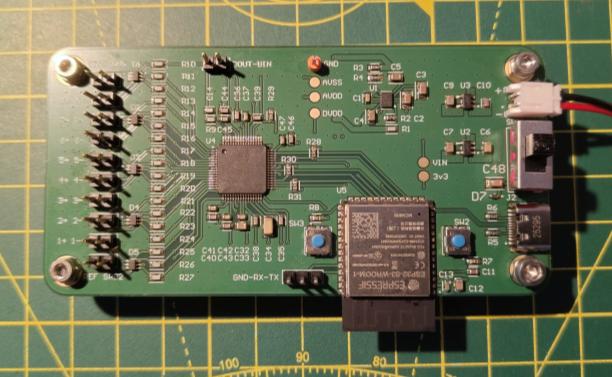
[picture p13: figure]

Figure 15: Unassembled PCB (left), and assembled PCB (right)

### 4.5. Mechanical Design

For the final stage of the design process, a custom enclosure, shown in Figure 16, was designed in Autodesk Inventor to house the electronics. The intention was to elevate the PCB from the work surface, as well as providing a removable lid to protect the device when in transport.

The PCB is bolted to the base through its M3 mounting holes. When open, the top of PCB has been left entirely uncovered, facilitating easy access to the pin headers, buttons and test points, as well as allowing airflow around the ESP32 for better thermal performance. Once again clearance has been given under the ESP32-S3 antenna, as well as around the USB and JST connectors to allow for easy access.

The lid is locked into place using a snap fit, created by four 2.5mm dimples on the base, and corresponding divots on the inside lid. The lid has a lip running around its midpoint, such that when combined with the lip on the bottom of the base, gives the user grip points, allowing for easy removal.

The enclosure was 3D printed on a Formlabs SLA (stereolithography) printer, with white resin V4.1.

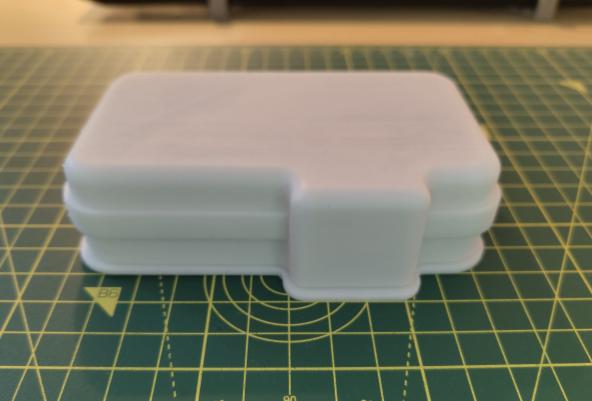
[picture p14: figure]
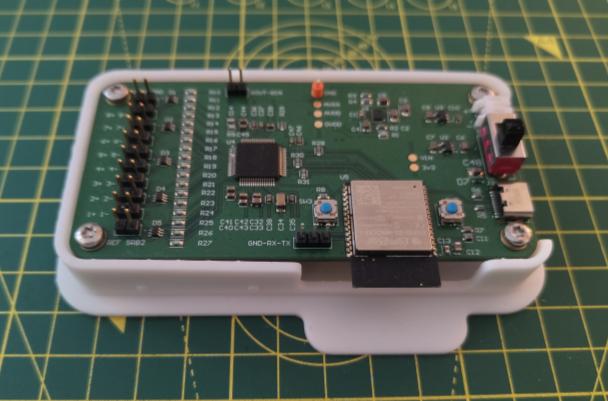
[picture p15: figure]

Figure 16: PCB enclosure with lid off (left) & lid on (right)

As previously mentioned, EEG signals have a magnitude of the order of microvolts, and thus are challenging to measure. Therefore, initial testing focuses on measuring larger biopotentials, in order to prove basic functionality of the system, and bring to light any unexpected issues. Only after this EEG testing is carried out.

### 5.1. Electromyography (EMG) Testing

Electromyography measures the electrical activity of skeletal muscles, specifically by measuring the superposition of Motor Unit Action Potentials (MUAPs), generated during voluntary contraction. Surface EMG can range between ±5000 µV, and directly reflects the force output of the involved muscle, as exertion of greater force increases both the recruitment and firing frequency of the MUAPs [58].

For the initial test of the EEG module, a forearm EMG test was carried out, where the active electrode was placed on the muscle belly of the medial aspect of the right forearm, specifically targeting the flexor digitorum superficialis. The reference electrode was placed on the back of the right wrist, so that it is on electrically inactive tissue, while the bias was placed on the back of the right hand [59]. The electrodes were applied using the following procedure [58], [60]:

1. Skin at electrode locations wiped with 70% Isopropyl Alcohol (IPA) wipes, to remove oil and sweat.
2. Skin rubbed with woven gauze swabs, to remove dead skin cells, dirt, and residual IPA.
3. Electrode cups filled with Ten20 conductive paste to form a dome shape.
4. Electrodes affixed to target locations using medical tape
5. Electrode lead wires taped to arm with sufficient slack to prevent mechanical pulling and provide strain relief.

To evoke EMG responses of varying magnitudes, the subject clenched their hand at three distinct velocities: fast, medium, and slow. The raw data was recorded using the LSL Lab Recorder application, and was subsequently processed in python, where a 50 Hz notch filter was applied to eliminate mains frequency interference, and a bandpass filter (20 – 125 Hz) was used to attenuate baseline and high frequency noise. Figure 17.1 shows a labelled example of an EMG recording from the biceps brachii [58], illustrating a noise free baseline, interrupted by EMG spikes of random shape, establishing a morphological example for this test to recreate. The test setup can be seen in Figure 17.2, where the two electrodes shown are reference and bias.

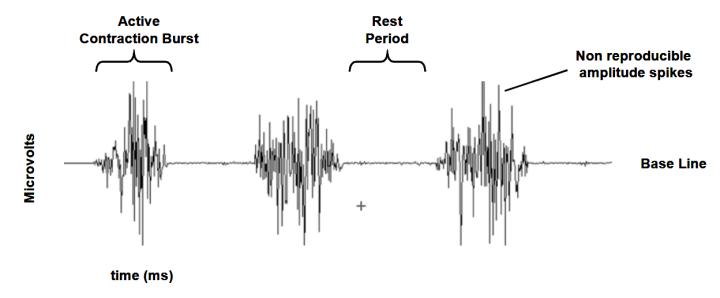
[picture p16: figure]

Figure 17.1: Example EMG Reading [58] | Figure 17.2: EMG test setup (showing ref & bias)

Figure 18 shows the recorded EMG results, and demonstrates that the system successfully captured the physiological relationship between contraction speed and motor unit recruitment. During the fast contraction, a dense cluster of MUAPs can be seen overlayed on top of each other, with an amplitude of ±1500 µV. As the amount of force decreased, the peak amplitudes proportionally reduced to ±1000 µV for the medium speed contraction, and ±400 µV for the slow contraction. Crucially, the periods of rest between contractions demonstrate a flat baseline, proving that the system is working as intended.

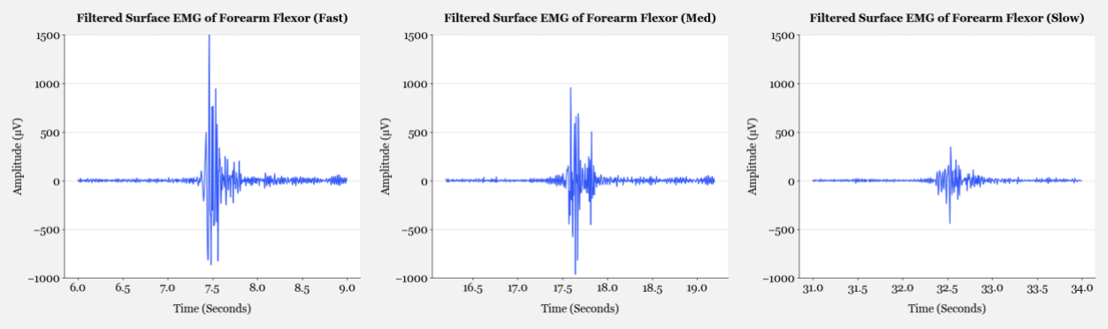
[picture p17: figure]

Figure 18: EMG hand clench test results (fast, medium, slow)

### 5.2. Electrocardiography (ECG) Testing

The initial EMG test was followed up by a supplementary ECG test, in order to validate the system’s ability to accurately capture biopotentials with distinct, recurring morphological features, as opposed to random bursts of muscle activity. Additionally, ECG waves are typically slightly smaller than those from EMG, at around ±2000 µV.

Electrocardiography measures the electrical activity of the heart, and is most commonly used for the assessment of cardiovascular disease. Figure 19 illustrates the basic structure of an ECG wave, where each feature corresponds to specific stages of atrial and ventricular depolarisation and repolarisation [61]. Data acquisition was conducted using the standard Einthoven’s Triangle
configuration. The active and
reference electrodes were
positioned on the right and left wrists, while the bias electrode was placed on the right ankle. Unlike EMG, where the
reference is placed at a point of electrical neutrality, the heart can be measured as a single time-varying dipole, and thus a differential signal can be read between the right and left arms [18, p. 231]. The skin
preparation procedure outlined
in the previous section was also

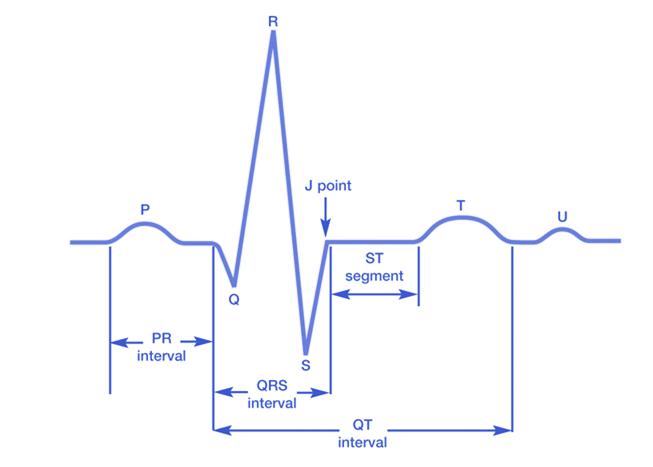
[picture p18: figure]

adhered to in this test. | Figure 19: Simplified and labelled ECG wave [61]

Figure 20 presents the filtered ECG waveforms captured during this test. Once again a 50 Hz notch filter has been applied, but this time paired with a bandpass of 0.5 – 40 Hz, in order to preserve the parts of the signal that exist in the lower frequencies [62]. The P wave, QRS complex, and T wave can be clearly seen, occurring approximately every second, corresponding to a healthy resting heart rate of 60 BPM. Overall, the system has recorded a clean ECG wave, once again verifying its performance.

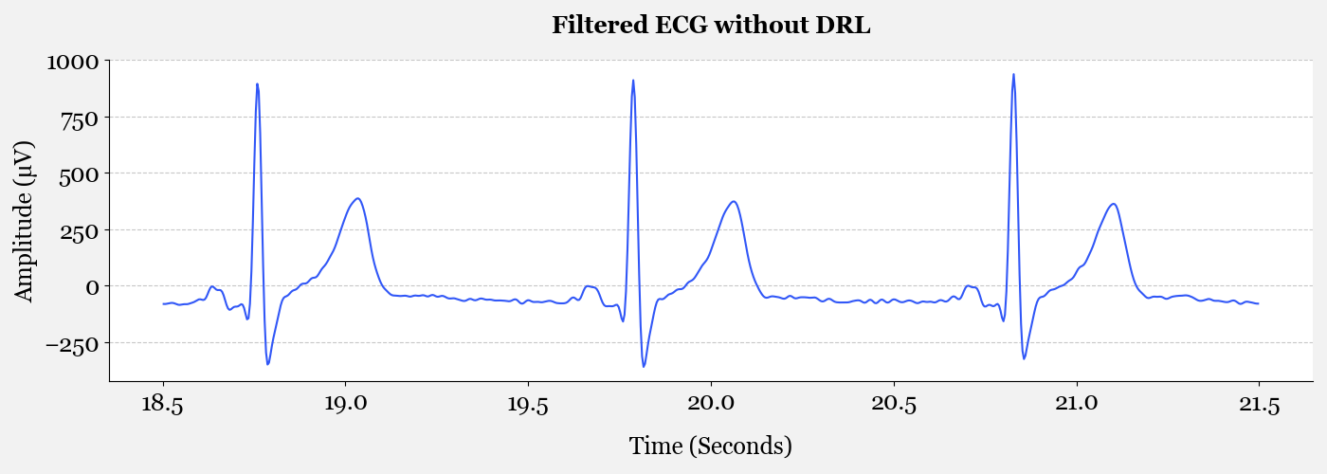
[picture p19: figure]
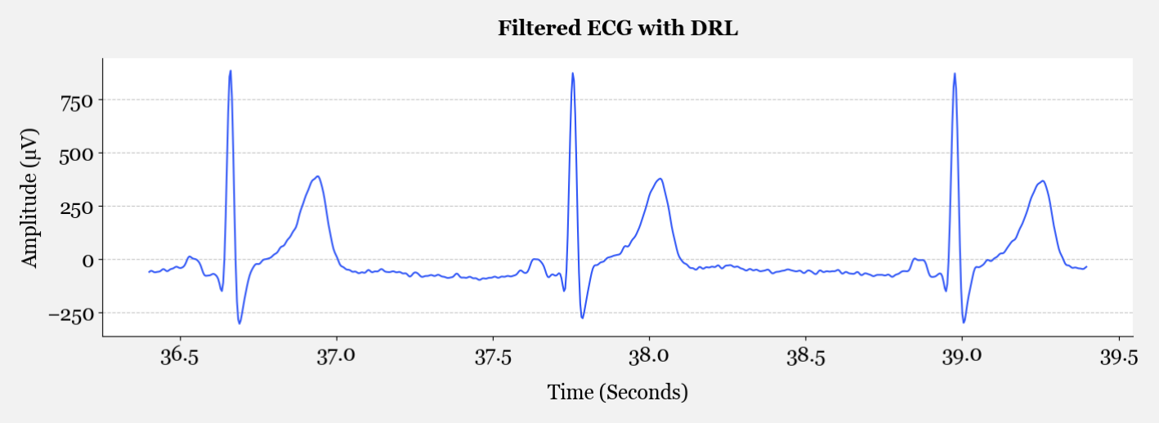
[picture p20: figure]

Figure 20: ECG test results, with and without driven right leg enabled

Furthermore, Figure 20 evaluates the impact of the driven right leg circuitry, contrasting recordings with the DRL disabled (top) and enabled (bottom). Surprisingly, activating the DRL slightly degraded the signal quality, introducing marginally more high frequency noise into the waveform. This observation aligns with the findings of Gomez-Clapers et al. (2011) [63], who suggested that in isolated, battery powered amplifiers with high CMRRs, the use of a DRL can increase differential-mode interference, while providing no real benefit, as common mode noise is already at a minimum. This is because the DRL redistributes how power-line currents flow through the body in an unpredictable way. Therefore, subsequent testing should be conducted with the DRL disabled, or should at least compare results with and without the DRL.

### 5.3. Alpha Wave Test

Alpha waves are 8 to 12 Hz oscillations that typically occur in relaxed states, with minimal mental activity [64]. It was initially believed that the presence of alpha waves reflected rest or idling, however contemporary research demonstrates that they represent the functional inhibition of parts of the brain not needed for specific tasks, and more broadly the allocation of computational resources within the brain [65]. As the most dominant oscillation in the human brain [66], alpha waves provide an ideal physiological benchmark for validation of the EEG module.
To capture these signals, active electrodes were placed at O1,
O2, and Oz, in accordance with the 10-20 system. This
configuration targets the occipital lobe; the primary centre for visual processing. The reference and bias electrodes were placed on the electrically quiet left and right earlobe. Once again electrodes were applied using the process outlined in Section 5.1, this time held in place with a section of tubular bandage. The experimental setup can be shown in Figure 21. The experiment leveraged the alpha blocking effect, whereby alpha wave amplitude is significantly attenuated when the eyes are opened [67]. The test consisted of a 20 second baseline period, where the subject fixated on a blank wall,
followed by an auditory cue to signal the closing of the eyes
for another 20 seconds. To ensure precise timing of the data

collection, the test script pushed synchronisation markers to a dedicated LSL stream, marking the start and end of each phase of the experiment.
Following data acquisition, a 50 Hz notch filter and a 1 to 50 Hz bandpass filter were applied. The power spectral density was then obtained using Welch’s method, which divides the data into windowed segments, takes the discrete Fourier transform of each section, and then averages the resulting spectra [1, p. 96] [68]. This averaging process has the benefit of cancelling random noise, whilst preserving continuous signals. The resulting spectral comparison is presented in Figure 22.

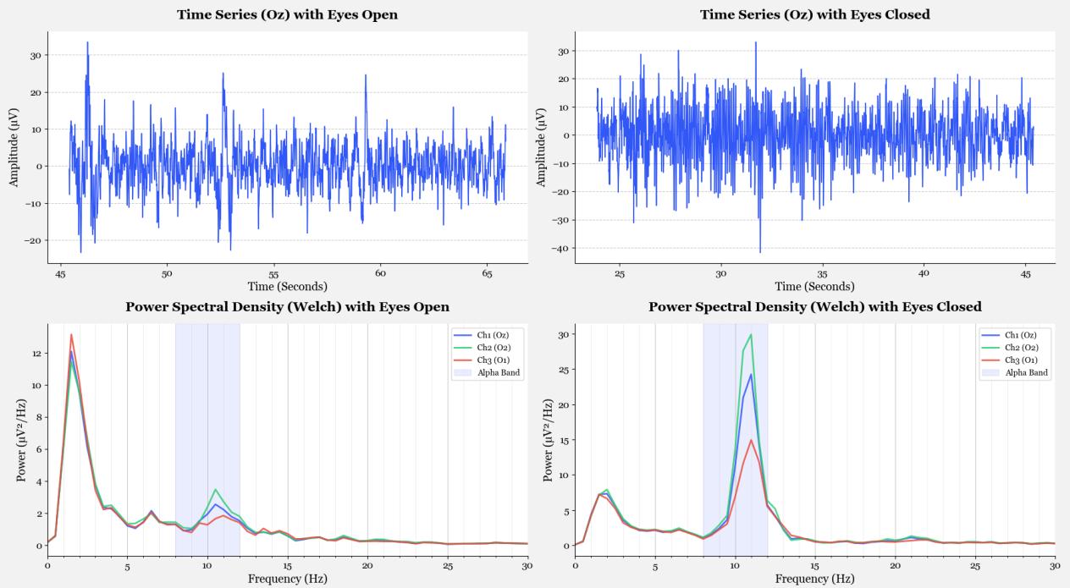
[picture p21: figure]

Figure 22: Time and frequency domain comparison of occipital alpha waves recorded with eyes open vs closed

Figure 21: Alpha wave test setup

As anticipated, there is a significant increase in alpha wave power during the eyes closed section of the test, with the greatest magnitude seen at the O2 position. This aligns with findings from J. Samaha & B. Postle (2015) [69], who similarly observed that alpha power peaked at the O2 position during their investigation into the temporal resolution of visual perception. The successful acquisition of alpha waves represents a critical milestone in validating the effectiveness of the proposed EEG module.

### 5.4. SSVEP Test

The next verification phase involved the detection of steady state visually evoked potentials (SSVEPs), which are evoked responses induced by flickering visual stimuli [70]. An SSVEP response appears as an increase in the amplitude at the fundamental frequency of the presented stimuli, often accompanied by peaks at its harmonics. As well as being used in neuroscience, to diagnose visual pathway and brain mapping impairments, SSVEPs are often used as a basis for BCI applications [24]. For example in BCI spellers, users navigate interfaces by focusing on specific flickering targets [71]. It thus follows that the reliable detection of SSVEPs is important for an EEG module designed to serve as a BCI teaching tool.

This test utilised the same occipital electrode configuration as the previous alpha wave test. Visual stimuli were generated on a 120 Hz monitor, using the Pygame library to alternate the screen between black and white in synchronisation with the monitor’s refresh rate. Target frequencies were achieved by changing the screen state after a specific number of frames, provided the target frequency was an even integer division of the 120 Hz refresh rate. It is for this reason that SSVEP responses were tested at 6, 7.5, 10, 12, 15, 20, 24 and 30 Hz. For each test the subject would stare at a marker on a black screen for 5 seconds, before being presented with the flickering stimuli for 10 seconds. Once again, LSL markers were used to precisely timestamp the beginning and end of each test stage.

Figure 23 (next page) shows the Fast Fourier Transform (FFT) of the filtered EEG data captured from each test. To prioritise frequency resolution over noise reduction, a standard FFT was used in place of Welch’s method. For each stimuli frequency we can observe the resulting peak in the EEG data, and at lower frequencies, including 6, 7.5 and 10 Hz, harmonic peaks are also present. The most powerful responses were elicited at 12 to 15 Hz, which is expected as these frequencies align closely with the alpha wave frequency range, perhaps demonstrating a resonance phenomenon [70]. At the extremes of the tested spectrum (6 & 30 Hz), the response has decreased in magnitude.

While the SSVEP detection was largely successful, specific anomalies can be observed in the 20 and 30 Hz tests, where despite the presence of a target frequency peak, there are other dominant frequencies. Because these artifacts were repeatedly observed at these frequencies with this specific visual setup, and did not occur with alternative testing configurations, they are likely due to limitations of the software-based test setup leading to errors in the presented visual stimuli. For instance, dropping frames would alter the effective frequency displayed to the user. It is for this reason that future iterations of this test would be better conducted by flickering an LED driven by a microcontroller to guarantee accurate stimulus frequencies.

Overall, the module’s ability to isolate SSVEP frequencies validates the systems performance, and confirms its readiness for use in BCI-applications.

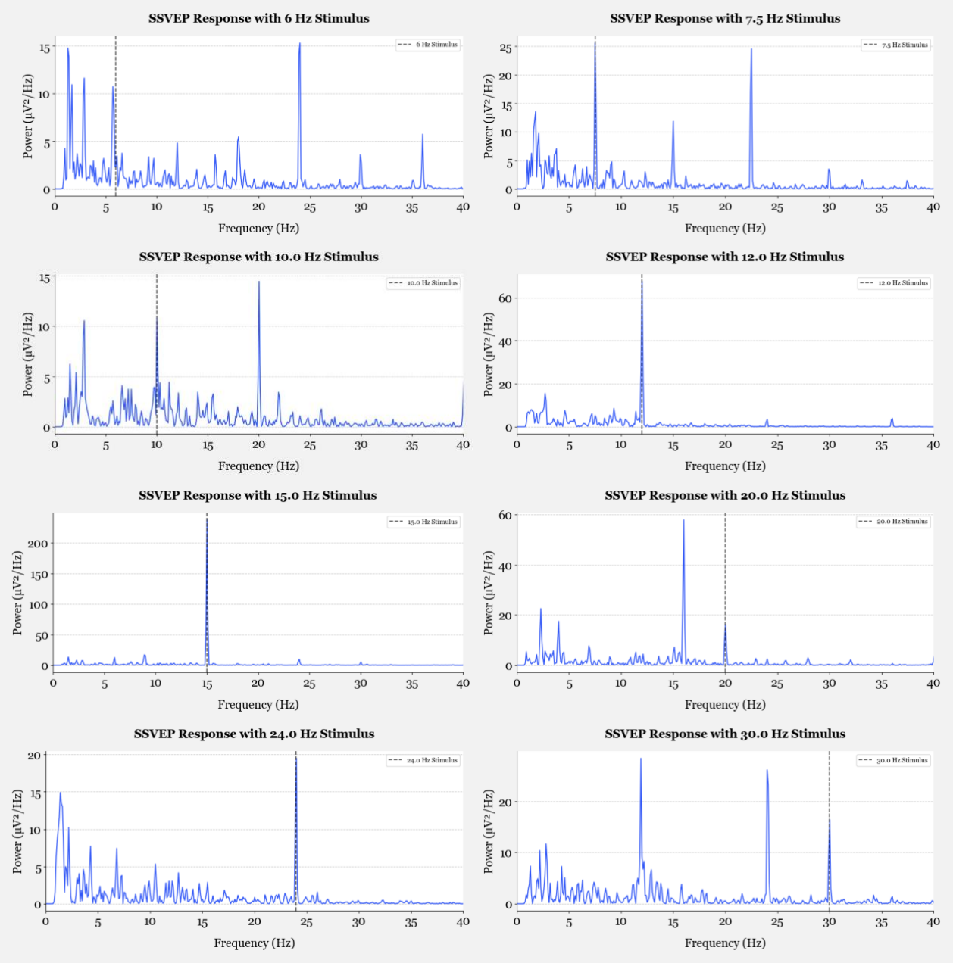
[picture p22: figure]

Figure 23: SSVEP response spectra with varying stimuli

### 5.5. P300 Test

The P300 is a positive deflection occurring approximately 300 milliseconds after a subject detects an informative, task-relevant stimulus [38]. It is most commonly elicited through the use of an auditory oddball paradigm, where the subject is required to count mentally, and to distinguish a more infrequent target tone from a nontarget stimulus [72]. The P300 is produced by a distributed network of brain processes associated with attention and memory operations, although there is not yet a clear understanding of exactly how and why the brain produces the P300 [25].

In contrast to alpha waves and SSVEPs, the P300 is a specific time domain waveform, and thus accurate P300 detection presents a greater challenge for the EEG module. In addition, P300 ERPs have long been used as the basis for BCI systems, for instance Farwell and

Donchin’s P300 speller (1988) [73], which relies on a P300 being produced when a letter the subject is looking at is flashed.

The subject was played a recording consisting of 1000 Hz standard tones, and 2000 Hz target tones. In total 100 tones were played at intervals between 1.4 and 1.8 seconds, of which 20 to 30 were the target tones. The resulting responses to the standard tones and the target tones were notch filtered at 50 Hz, bandpassed between 0.5 & 20 Hz, and subsequently averaged to remove random noise. These results are shown in Figure 24, where the standard error of the mean has also been plotted to show the variance of the results.

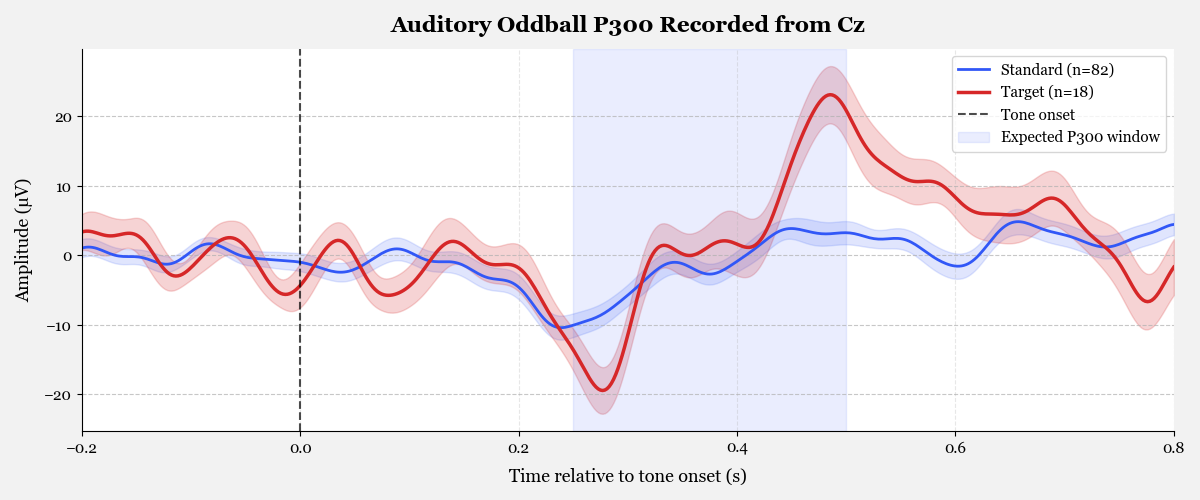
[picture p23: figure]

Figure 24: ERP response evoked from target tones (n=18) compared to standard tones (n=82)

Figure 24 shows a clear positive deflection within the expected P300 window, peaking at 23 µV at 485 ms, during which the standard waveform is at the baseline. The P300 waveform has a marginally larger standard error of the mean, however this is expected as P300s show high variability due to changes of cognitive state within an experimental session [74].

For the sake of comparison, Figure 25 shows an example P300 waveform, from a study comparing different P300 paradigms with different aged subjects [72]. These results were obtained with an almost identical experimental setup, but represent the average from twenty 100-tone trials, taken from children aged 12-14 years old.

Figure 25: Example P300 recording averaged from 20 individuals [72]

In both Figure 24 waveforms, an N2 peak can be seen in the region of 200 to 300 ms. These appear across both the standard, and target waves due to the fact they are sensory, rather than cognitive evoked potentials. The recorded P300 has very similar morphology to the example shown in Figure 25, and subtle differences can be attributed to the greater number of trials the example data is averaged across, as well as the fact that P300 can vary depending on the subject and the conditions.

In addition, other time domain ERP tests were conducted, including tests for flash VEPs (visually evoked potentials), pattern reversal VEPs, as well as half-field pattern reversal VEPs, the results of which can be found in Appendix G. Taken together with the results of the P300 test, they confirm the system’s ability to measure specific time series EEG waveforms, and provide results aligned with those expected from the literature. This test completes the chain of verification, and proves the module is capable of being used as a brain computer interface, particularly since SSVEPs and P300s are commonly used as the basis for BCI systems.

Beyond standard BCI applications, the P300 can also be used in a forensic capacity, as a method of identifying concealed information. The results of carrying out such a test are detailed in Appendix H, which is intended to serve primarily as a demonstration of this application, rather than another stage of verification.

### 6.1. Evaluation Against Objectives

The overall aim of this project was to design, build and validate a low-cost, open-source EEG module capable of safely measuring known EEG features for educational and research applications. Evaluating the system against the four core objectives outlined in section 2.2 demonstrates that the project has been largely successful, and can genuinely help bridge the gap between expensive commercial EEG headsets, and the poorly documented academic prototypes.

Objective 1: Hardware Design and Assembly | Fully Met
A custom EEG PCB module was designed, assembled, and tested, integrating an ADS1299 analogue front end with an ESP32-S3 to accurately measure EEG signals from input electrodes, and transmit them to an external computer. Patient safety is maintained through the use of battery power and wireless communication. Most importantly, the low-cost constraint was satisfied, with a total component cost of £68.07 for 4 EEG channels, or £99.92 for 8 channels, representing an order of magnitude reduction in cost compared to commercial equivalents, like the OpenBCI Cyton.
Objective 2: Software and Firmware Integration | Fully Met
A robust data transmission pipeline has been implemented, capable of recording EEG data at 500 SPS, without any packet loss, and sending the data to the Lab Streaming Layer. This allows the user to use free LSL applications including BrainVision, Lab Recorder, and OpenViBE, to view and filter the data in real time, or to record the data alongside time stamped external stimuli.
Objective 3: System Validation | Fully Met
The system’s EEG acquisition capabilities were evaluated across a range of human biopotentials, starting with noise free recordings of EMG and ECG waves, and ending with the successful detection of EEG features commonly used in BCI systems, including alpha waves, SSVEPs, and P300s. In particular the acquisition of evoked potentials of similar scale and morphology to those in the literature reinforces the system’s readiness to be used as a brain computer interface. Additionally an input referred noise of 1.10 µVpp was measured with the channel inputs shorted, demonstrating a comparable performance to the ADS1299 datasheet.
Objective 4: Open-Source Documentation | Partially Met
Contained in the appendices of this report are the complete firmware and software source code, as well as the Altium schematic, and BoM for the module. However, a complete, open-source, project repository, that would also contain Gerber files for the board layout and STL files for the enclosure, has yet to be created, due to the fact there are minor improvements that ideally would be made before the designs are released to the public (see section 6.4). Moreover, due to timing constraints, user guides and documentation have not yet been written.

### 6.2. Suitability for Target Application

This prototype was developed to address a gap within the BCI landscape: the lack of a truly low-cost, fully open source, and easily reproducible EEG module. At present, should you wish to purchase an EEG machine, you are forced to spend hundreds of pounds on what are often fully integrated, inflexible systems. By utilising the industry standard ADS1299 analogue front end, the system can achieve the signal fidelity of a premium headset, but at a fraction of the hardware cost.

One area where this high cost is a particularly large barrier is in educational environments, where the extreme cost of EEG hardware puts it out of reach of most University modules and research projects. Table 6 compares the price of the proposed system to the OpenBCI Cyton board, when purchasing EEG modules for a class of 20 students. The total price is diminished from a completely unaffordable £18,660, to £1,402.65. While still making for an expensive purchase, this is significantly closer to being a realistic option for a university, although it would also require time from a lab technician for board assembly.

Table 6: 20 module price comparison vs OpenBCI Cyton Board

| Proposed EEG Module | OpenBCI Cyton
Individual Cost | £68.07 | £933
Total Component Cost | £1,361.40 | £18,660
Fabrication Cost | £41.25 (JLC PCB) | £0.00
Total Cost | £1,402.65 | £18,660

Furthermore, the component cost of £68.07 is well within the budget for a typical university final year project, or group business and design project, opening up possibilities for students to implement brain computer interfaces into their engineering projects, or to gather EEG data as part of a study. This hands-on experience would be invaluable for teaching students about brain computer interfaces, as well as broader topics such as signal processing, feature extraction and machine learning, all of which are fundamental to BCI technology.

The module itself is well suited for use in these kinds of educational environments, with standard 2.54 mm pin header electrode connections allowing for the use of any type of electrode, which can subsequently be placed in any configuration. This is contrary to devices like the Muse 2, or Emotiv Epoc X, which lock you into using a single type of electrode, in fixed positions on the head. On the software side, the integration with the Lab Streaming Layer makes it easy to synchronise tests involving external stimuli, as well as giving users the flexibility to view and process the data how they see fit. In particular, the OpenViBE toolbox is particularly well suited, allowing students to process the data in real time with an intuitive drag and drop interface.

### 6.3. Limitations and Sources of Uncertainty

While the prototype successfully met its core objectives, several limitations and sources of uncertainty were identified during the testing process, highlighting areas for refinement.

The first major source of uncertainty is the lack of quantitative metrics by which to assess the EEG module. While extensive EEG testing was carried out, proving that the module could discern several well-known EEG features, the testing process would greatly benefit through comparisons with commercial and clinical EEG machines, as well as multi-subject trials. Running the same tests on other proven EEG hardware would reduce any uncertainty in the test results, for example proving that the anomalous SSVEP results acquired at 20 and 30 Hz resulted from an inadequate test setup, rather than a hardware flaw. Moreover, having a true benchmark for each of the conducted tests would allow for a better assessment of exactly how accurate each of the results are, as opposed to the current, somewhat binary system of just checking if a feature can be detected at all. This holds true particularly for tests like the P300 test, where the results typically show a large person to person variance.

Another source of uncertainty are potential time offsets in the recorded data. Results from the flash VEP test and pattern reversal VEP test, located in Appendix G, as well as the P300 test, show the recorded wave consistently occurring around 25-100 ms later than set out by the literature. A possible reason for this delay is that BLE is not a particularly time sensitive communication protocol, and could be introducing delay or jitter to the recorded data. A possible solution to this would be to timestamp the data as soon as it is read by the ESP32, and force the LSL to use this timestamp, rather than letting it create one from the PC’s clock when being pushed. Another limitation caused by BLE is a 500 SPS data limit, whereby if the ADS1299 sampling rate is increased to 1000 SPS, packets begin to be dropped. While this is not a major drawback in an educational environment, as 500 SPS is more than adequate to record standard EEG features, it prevents the user, should they wish, to record higher frequency data.

Finally, testing of the EEG module has been conducted solely with gold cup electrodes, which while extremely cheap and reliable, are not particularly well suited to an educational environment. This is because the required skin preparation and application of conductive paste can be a lengthy and slightly messy process, which would leave the user with residual paste in their hair after testing. Moreover, purchasing conductive paste and other skin preparation equipment incurs additional costs, in particular the industry standard Ten20 paste costing a minimum of £20 per 228g tub. The use of dry electrodes would entirely negate this issue, allowing for fast and easy application, at the cost of signal fidelity. For this reason, it would be worth sourcing a set of dry electrodes, and testing the capabilities of the system with these in comparison to gold cup electrodes.

### 6.4. Future Work

To evolve the initial prototype into a system that is ready for more widespread deployment, several avenues for future development have been identified.

Firstly, as is often the case with PCB design, there are several small improvements that should be made to the board before the design is finalised:

Power Path Management | High Priority
The most pressing change is adding power path management, such that the USB-C power rail does not power the ADS1299, only allowing the user to record data while the device is battery powered, and forcing electrical isolation. For initial testing and debugging it was helpful to be able to power the entire system over USB, however relying on the user to manually switch to battery power is not a sensible long term design choice.
Design for Manufacture | High Priority
In the current design, a limited number of components have been placed on the bottom layer in order to reduce PCB size. However, this unnecessarily lengthens the assembly process, as these components then need to be hand soldered. For the same reason, where possible through hole components should be replaced by surface mount counterparts. Both of these changes also reduce the cost of purchasing the board assembled.
On-Board Charging | Medium Priority
Adding battery charging functionality to the board, for instance with a low-cost constant current/constant voltage charging IC like the MCP73871, would remove the need for external LiPo charging modules. This is a straightforward change, as the board already has a USB-C port that could be used for charging. Additionally, the ICs power good pin could be used to accomplish the power path management change, by routing it to the enable pin of the ADS1299 LDOs.
Daisy Chain Functionality | Low Priority
The ADS1299 can be set up such that daisy chaining multiple modules together is possible. While not strictly necessary for use in education, exposing the correct daisy chaining pins, and allowing the user to create a system with more than 8-channels, would open up a small amount of additional applications.

Aside from hardware changes, there are a couple of software and firmware changes that could be implemented. Firstly, as discussed in the above section, it would be worth changing the firmware to timestamp the ADS1299 samples as soon as they are read, to remove the potential for timing offsets. Secondly, it would be beneficial to create a simple GUI for the python host script, removing the need for the user to interact with the windows terminal to see the lead off bits and other status information. This GUI could also be expanded to allow the user to change ADS1299 setup registers, rather than having to change them manually in the ESP32-S3 source code, facilitating straightforward adjustment of settings including PGA gain, or driven right leg derivation channels. This would involve the implementation of bidirectional BLE communication.

Finally, the most important piece of future work is the compilation of all of the source code, schematics, Gerber files and STL files, into a comprehensive repository, allowing for the project to be easily reproduced, and thus made accessible to other educational and research institutions. This must be paired with thorough documentation, explaining how the system was created, how it should be used, and notifying the reader of any identified limitations. The repository could also include the test scripts used to detect EEG features identified in the report, to act as demonstrations of the system, and aiding the user in their own development.

### 6.5. Conclusion

In conclusion, this project has delivered a low-cost, wireless EEG module that addresses a clear gap in the current BCI landscape, bringing down the cost of EEG technology to a level suitable for educational deployment. With a minimum component cost of £68, the proposed system is significantly cheaper than any comparable commercial offerings, and has been validated across a range of features that underpin BCI systems, including alpha waves, SSVEPs and P300 responses. The combination of the ADS1299 analogue front end, the ESP32-S3 BLE capable microcontroller, and the LSL integration, produces a flexible, electrode agnostic system that would be well positioned for adoption into student-led projects and undergraduate teaching. With the refinements outlined above, particularly the PCB design changes, the ESP32-S3 timestamping, and the open-source repository, the module is ready to make hands-on EEG learning substantially more accessible.

# 7. Project Review

### 7.1. Project Scheduling and Scoping

Generally speaking, a waterfall development process has been followed during the project. This process was chosen due to the fact the project has clearly defined requirements, and is highly structured by nature [75]. For instance, once the finalised PCB design is sent for manufacture, it becomes difficult to make large changes to previous design stages. The overall project structure, and its adherence to the 5 stages of the waterfall model, can be seen in Figure 26.

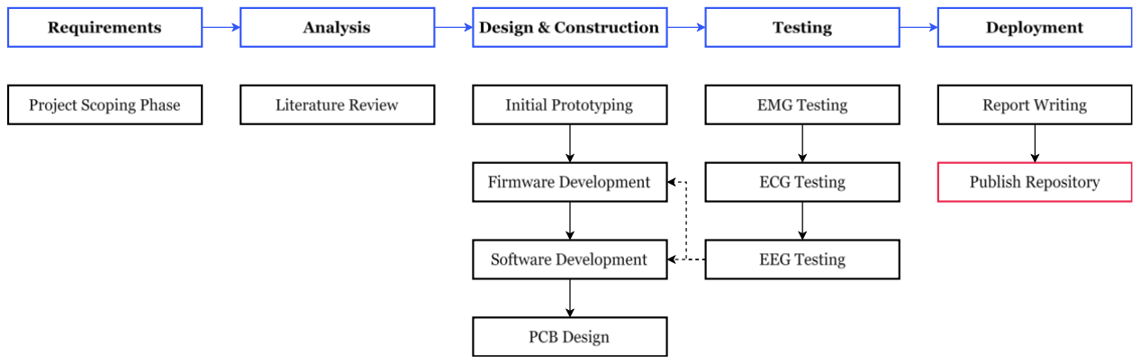
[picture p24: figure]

Figure 26: Overall project structure, divided into waterfall stages

During the project scoping phase, a Gantt chart was created, however the project fairly quickly deviated from the original development plan, as the need for a custom PCB, rather than a development board prototype became apparent. The introduction of a PCB design stage placed stress on the project timeline, as naturally the board took time to manufacture and assemble. This removed any margin for error within the project, as in the case where there was a fault in the PCB design, there would be insufficient time and budget to get it manufactured again. Fortunately, the PCB design and assembly was one of the main successes of the project, with the design functioning exactly as intended. This is what facilitated the acquisition of microvolt EEG signals, ultimately underpinning the project’s overall success. However, it is still worth noting that with proper planning, this pressure could have been somewhat alleviated.

### 7.2. Supply Chain and Logistical Challenges

The most significant obstacles during the project arose from difficulties sourcing critical components. For instance, the literature review had established the ADS1299 as the standard for low-cost EEG boards, however its evaluation module was out of stock for multiple weeks. Due to the sequential structure of the waterfall process, this delay to the start of the development process propagated through to each subsequent stage. Furthermore, sourcing EEG specific components, like Ten20 conductive paste, or gold cup electrodes, from UK suppliers proved difficult, with both of these taking weeks to be delivered, and without which the project would not have been a success. The effects of these delays were then compounded when an administrative error resulted in an unforeseen weeklong delay of the PCB components.

Once again, this has highlighted the importance of proper scheduling. Incorporating buffer periods into the project schedule to allow for procurement delays, as well as ordering critical components earlier in the development cycle, would have resulted in more time for the latter stages of the project, as well as a greater margin for error were something to go wrong. Ultimately, despite the project’s overall success, better time management and planning may have resulted in Objective 4: Open-Source Documentation, being fully complete, as there would have been sufficient time to create documentation.

### 7.3. Budgetary Constraints

A final challenge throughout the project lifecycle was the management of the development budget. The initial allocated budget of £250 quickly proved insufficient for the required hardware prototyping stage, with the ADS1299 evaluation module alone costing £194.23. A budget extension of £60 was secured from the university in order to afford the components to populate the PCB, however, to complete the system integration and testing, further expenditure was necessary. From this point the Ten20 conductive paste, as well as gold cup electrodes were purchased by my project supervisor, the PCB manufacture was financed through personal funds, while the enclosure was printed for free by the university. The full project expenditure can be found in Appendix A.

This experience highlighted the fact that the development of a low-cost product can far exceed its eventual unit cost. While the final BoM for a 4-channel module comes to just £68, the ADS1299 evaluation module consumed over three times the cost, before a single component had been ordered. A more thorough budgetary forecast at the start of the project would have removed the need for personal expenditure and unplanned funding requests.

First, I would like to thank my supervisor, Dr Nic Zhang, for providing a project that is both interesting and engaging from a technical point of view, but also due to its broader scientific application. Learning about electroencephalography, and working up to recording my own EEG data, has been a genuinely enjoyable and rewarding experience, and his guidance and support throughout the project are greatly appreciated.

I would also like to thank GE Aerospace Bristol, my placement company, for allowing me to return to use their electronics facilities to assemble my PCB. In particular, I am grateful for Jamie Adams and Lorenzo Colo’s assistance and advice during the assembly process, which was invaluable for the completion of my project.

Finally, I would like to thank my housemate Tom Kirsch, for volunteering as a test subject, as well as Rebecca Loundes and Roberta Griffiths for assisting me with electrode application throughout the testing process.

Generative AI Statement

I acknowledge the use of Google’s Gemini 3.1 Pro model during the development of the project and writing of this report. Specifically, the tool was used to assist with the following purposes:

- Identifying relevant literature and summarising background concepts.
- Proofreading and refining grammatical clarity of the report.
- Assisting with troubleshooting and debugging C++ and Python code.

All original ideas and decisions presented within this document are entirely my own, and all factual information has been properly referenced.
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

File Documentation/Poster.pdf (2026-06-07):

# Prototyping a

low - cost EEG machine

## Xavier Asghar – Meng Final Year Project – 2025/26


## The Hardware


- Up to 8-channels of electrodes can be connected to the input pin headers
- Texas Instruments ADS1299 EEG Analogue Front-End amplifies and digitises the EEG signal at up to 500 SPS
- The ESP32-S3 then reads the EEG data, and transmits it to a a host computer using Bluetooth Low Energy
- A python script on the host computer unpacks the EEG data, and pushes it to the Lab-Streaming-Layer, for visualisation and recording
- The module is battery powered to ensure patient safety via electrical isolation
- The built in driven right leg helps to cancel common-mode noise

## Introduction

- Electroencephalography (EEG) is a non-invasive method of recording electrical activity in the brain
- EEG has many developing applications, particularly involving brain-computer interfaces (BCIs)
- However, commercial EEG headsets are prohibitively expensive, costing approximately £1000, while clinical EEG machines cost even more
- This project aims to lower the cost of EEG technology, such that it can be utilised in an educational environment, for instance in student research projects, or coursework activites.

# What it Detects


# Conclusions


- The proposed system has been proven to accurately measure EEG features commonly used in BCIs
- The module has a minimum component cost of just £68
- This represents an almost order of magnitude reduction compared to commercial EEG systems, like the OpenBCI Cyton module (£940), or the Emotiv EPOC X headset (£885)
- With this board it would now be feasible to use EEG technology in a final year project, or give to students as part of a coursework task
Alpha Waves • Alpha waves are 8 – 12 Hz oscillations, recorded from the occipital region of the cortex, from an awake subject with their eyes closed. • They are thought to represent the functional inhibition of the brain [66] | P300 Wave • The P300 is a positive deflection occurring approximately 300 ms after a subject detects an informative, task relevant stimulus [38] • The exact origins of the P300 are not yet fully understood.


Steady State Visually Evoked Potentials (SSVEPS) • SSVEPs are evoked responses induced by flickering stimuli, appearing as an increase in amplitude at the frequency of the stimulus [70] • SSVEPs are often used for BCI applications, e.g. BCI spellers | Concealed Information Protocol • The P300 can be used as a forensic tool for memory detection [78] • The subject chose a secret colour (green), and had to count a target colour (yellow). The response to different colour flashes has been recorded:


[1] ‘TMSi — an Artinis company — What Is the 10-20 System for EEG?’, TMSi — an Artinis company. Accessed: Apr. 17, 2026. [Online]. Available: https://www.tmsi.artinis.com/blog/the-10-20-system-for-eeg
[66] W. Klimesch, ‘Alpha-band oscillations, attention, and controlled access to stored information’, Trends Cogn. Sci., vol. 16, no. 12, pp. 606–617, Dec. 2012, doi: 10.1016/j.tics.2012.10.007.
[70] F.-B. Vialatte, M. Maurice, J. Dauwels, and A. Cichocki, ‘Steady-state visually evoked potentials: Focus on essential paradigms and future perspectives’, Prog. Neurobiol., vol. 90, no. 4, pp. 418–438, Apr. 2010, doi: 10.1016/j.pneurobio.2009.11.005.
[38] T. W. Picton, ‘The P300 wave of the human event-related potential’, J. Clin. Neurophysiol. Off. Publ. Am. Electroencephalogr. Soc., vol. 9, no. 4, pp. 456–479, Oct. 1992, doi: 10.1097/00004691-199210000-00002.
[78] L. A. Farwell and E. Donchin, ‘The truth will out: interrogative polygraphy (“lie detection”) with event-related brain potentials’, Psychophysiology, vol. 28, no. 5, pp. 531–547, Sep. 1991, doi: 10.1111/j.1469-8986.1991.tb01990.x.

[1]

Supervisor :
Dr Nic Zhang

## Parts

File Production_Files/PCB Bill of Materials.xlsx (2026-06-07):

Line # | Name | Description | Designator | Quantity | Manufacturer 1 | Manufacturer Part Number 1 | Supplier 1 | Supplier Part Number 1 | Supplier Unit Price 1 | Supplier Subtotal 1
 | C0603C474K4RACAUTO | Cap Ceramic 0.47uF 16V X7R 10% Pad SMD 0603 125C Automotive T/R | C1 | 1 | Yageo Group | C0603C474K4RACAUTO | Mouser | 80-C0603C474K4RAUTO | 0.32434 | 0.32434
 | GCJ21BR71C475KA01K | Multilayer Ceramic Capacitors MLCC - SMD/SMT 0805 4.7uF 10%, 16VDC, X7R 15% | C2, C3, C48, C49 | 4 | Murata | GCJ21BR71C475KA01K | Mouser | 81-GCJ21BR71C475KA1K | 0.27909 | 1.12
 | GCM21BR71C225KA64K | Ceramic Capacitor for Automotive 2.2uF ±10% 16VDC X7R 0805 Embossed T/R | C4, C5 | 2 | Murata | GCM21BR71C225KA64K | Mouser | 81-GCM21BR71C225KA4K | 0.16594 | 0.33189
 | GRJ21BR61E106KE01L | CAP CER MLCC | C6, C7, C9, C12, C33 | 5 | Murata | GRJ21BR61E106KE01L | Mouser | 81-GRJ21BR61E106KE1L | 0.05129 | 0.51291
 | CC0603KRX7R7BB105 | CAP CER 1UF 16V X7R 0603 | C10, C11, C35, C36, C38, C39, C40, C43, C44, C46 | 10 | Yageo Group | CC0603KRX7R7BB105 | Mouser | 603-CC603KRX7R7BB105 | 0.03696 | 0.3696
 | CGA3E2X7R1H104K080AD | Cap Ceramic 100nF 50V X7R 10% Pad SMD 0603 +125°C Automotive T/R | C13 | 1 | TDK | CGA3E2X7R1H104K080AD | Mouser | 810-C1608X7R1H104KEP | 0.09051 | 0.09051
 | C0603C152J1GACTU | CAP CER 1500PF 100V NP0 0603 | C14 | 1 | Murata | GRM1885C2A152JA01D | Mouser | 81-GRM1885C2A152JA1D | 0.07543 | 0.07543
 | C0603C102F5GACTU | CAP CER 1000PF 50V 1% NP0 0603 | C15, C16, C17, C18, C19, C20, C21, C22, C23, C24, C25, C26, C27, C28, C29, C30, C31 | 17 | Yageo Group | C0603C102F5GACTU | Mouser | 80-C0603C102F5G | 0.44578 | 7.58
 | C0603X104J4RACTU |  | C32, C37, C41, C42, C45, C47 | 6 | Yageo Group | C0603X104J4RACTU | Mouser | 80-C0603X104J4R | 0.10485 | 1.05
 | GRM31CR61A107MEA8L | Chip Multilayer Ceramic Capacitors for General Purpose, 1206, 100uF, X5R, 15%, 20%, 10V | C34 | 1 | Murata | GRM31CR61A107MEA8L | Mouser | 81-GRM31CR61A107MA8L | 0.35451 | 0.35451
 | TPD4E1B06DCKR | Quad 0.7-pF, Â±5.5-V, Â±12-kV ESD protection diode with 0.5-nA max leakage in SOT & SC70 packages | D1, D2, D3, D4, D5 | 5 | Texas Instruments | TPD4E1B06DCKR | Mouser | 595-TPD4E1B06DCKR | 0.72411 | 3.62
 | SD05T1G | Transient Voltage Suppressor Diode, for ESD Protection, 2-Pin SOD-323, Pb-Free, Tape and Reel | D6 | 1 | onsemi | SD05T1G | Mouser | 863-SD05T1G | 0.33189 | 0.33189
 | ESD5Z5.0T5G | ESD5Z5.0T5G Trans Voltage Suppressor Diode, 174W, 5V V(RWM), Unidirectional, 1 Element, Silicon | D7 | 1 | onsemi | ESD5Z5.0T5G | Mouser | 863-ESD5Z5.0T5G | 0.17349 | 0.17349
 | S2B-PH-K-S(LF)(SN) | Male Header, Pitch 2 mm, 1 x 2 Position, Height 4.8 mm, Tail Length 3.4 mm, -25 to 85 degC, RoHS, Bulk | J1 | 1 | JST | S2B-PH-K-S(LF)(SN) | Arrow Electronics | S2B-PH-K-S(LF)(SN) | 0.07596 | 0.07596
 | 217179-0001 | CONN RCP USB2.0 TYP C 24P SMD RA | J2 | 1 | Molex | 217179-0001 | Mouser | 538-217179-0001 | 0.62606 | 0.62606
 | TSW-102-26-F-S | 0.025" SQ Post Header, Through-hole, Vertical, -55 to 125 degC, 2.54 mm Pitch, 2-Pin, Male, RoHS | J3A, J3B, J3C, J3D, J3E, J3F, J3G, J3H, J3I, J3J, JP1 | 11 | Samtec | TSW-102-26-F-S | Mouser | 200-TSW10226FS | 0.23383 | 2.57
 | TSW-103-07-T-S | 0.025" SQ Post Header, Through-hole, Vertical, -55 to 105 degC, 2.54 mm Pitch, 3-Pin, Male, RoHS | J5 | 1 | Samtec | TSW-103-07-T-S | Mouser | 200-TSW10307TS | 0.09806 | 0.09806
 | MCT06030D1303BP100 | RES SMD 100 OHM 1% 1/8W 0603 | R1 | 1 | Vishay | MCT06030D1303BP100 | Mouser | 594-MCT06030D1303BP1 | 0.43749 | 0.43749
 | RT0603BRD07120KL | RES SMD 120K OHM 0.1% 1/10W 0603 | R2 | 1 | Yageo Group | RT0603BRD07120KL | Mouser | 603-RT0603BRD07120KL | 0.1056 | 0.1056
 | RT0603BRD07105KL | RES SMD 105K OHM 0.1% 1/10W 0603 | R3 | 1 | Yageo Group | RT0603BRD07105KL | Mouser | 603-RT0603BRD07105KL | 0.18857 | 0.18857
 | AT0603BRD07100KL | Thin Film Chip Resistors Automotive Grade 100kΩ 0.1% 25ppm/°C 0603 | R4 | 1 | Yageo Group | AT0603BRD07100KL | Mouser | 603-AT0603BRD07100KL | 0.24137 | 0.24137
 | RT0603FRE075K1L | RES SMD 5.1K OHM 1% 1/10W 0603 | R5, R6 | 2 | Yageo Group | RT0603FRE075K1L | Mouser | 603-RT0603FRE075K1L | 0.00603 | 0.06034
 | AC0603FR-7W10KL | RES 10kΩ 1.00% 0.2W 0603 | R7, R8, R28, R29, R30, R31, R32, R33, R34, R35 | 10 | Yageo Group | AC0603FR-7W10KL | Mouser | 603-AC0603FR-7W10KL | 0.0083 | 0.08297
 | MCT06030C1004FPW00 | RES SMD 100 OHM 1% 1/8W 0603 | R9 | 1 | Vishay | MCT06030C1004FPW00 | Mouser | 594-MCT06030C1004FPW | 0.09051 | 0.09051
 | MCT06030D2201BP500 | RES SMD 100 OHM 1% 1/8W 0603 | R10, R11, R12, R13, R14, R15, R16, R17, R18, R19, R20, R21, R22, R23, R24, R25, R26, R27 | 18 | Vishay | MCT06030D2201BP500 | Mouser | 594-MCT06030D2201BP5 | 0.05959 | 1.07
 | 1101M2S3CQE2 | SWITCH SLIDE SPDT 6A 120V | SW1 | 1 | C&K Components | 1101M2S3CQE2 | Mouser | 611-1101M2S3CQE2 | 4.19 | 4.19
 | 7914J-1-032 | SWITCH TACTILE SPST-NO 0.1A 16V | SW2, SW3 | 2 | Bourns | 7914J-1-032 | Mouser | 652-7914J-1-032 | 0.79954 | 1.6
 | 5003 | Test Point, Orange, 1-Pin THD, RoHS | TP1 | 1 | Keystone | 5003 | Mouser | 534-5003 | 0.25646 | 0.25646
 | TP | 2mm diameter circular test point, | TP2, TP3, TP4, TP5, TP6 | 5
 | LM27762DSSR | IC REG CHARGE PUMP ADJ DL 12WSON | U1 | 1 | Texas Instruments | LM27762DSSR | Mouser | 595-LM27762DSSR | 1.55 | 1.55
 | TLV75733PDBVR | IC REG LINEAR 3.3V 1A SOT23-5 | U2 | 1 | Texas Instruments | TLV75733PDBVR | Mouser | 595-TLV75733PDBVR | 0.24891 | 0.24891
 | TPS7A2033PDBVR | IC REG LINEAR 3.3V 300MA SOT23-5 | U3 | 1 | Texas Instruments | TPS7A2033PDBVR | Mouser | 595-TPS7A2033PDBVR | 0.24137 | 0.24137
 | ADS1299IPAGR | Low-Noise, 8-Channel, 24-Bit Analog Front-End for Biopotential Measurement, 16 KSPS, -40 to 85 degC, 64-Pin PQFP (PAG-64), RoHS, Tape and Reel | U4 | 1 | Texas Instruments | ADS1299IPAGR | Mouser | 595-ADS1299IPAGR | 64.87 | 64.87
 | ESP32-S3-WROOM-1-N8R8 | Bluetooth, WiFi 802.11b/g/n, Bluetooth v5.0 Transceiver Module 2.4GHz PCB Trace Surface Mount | U5 | 1 | Espressif | ESP32-S3-WROOM-1-N8R8 | Mouser | 356-EP32S3WROOM1N8R8 | 4.68 | 4.68

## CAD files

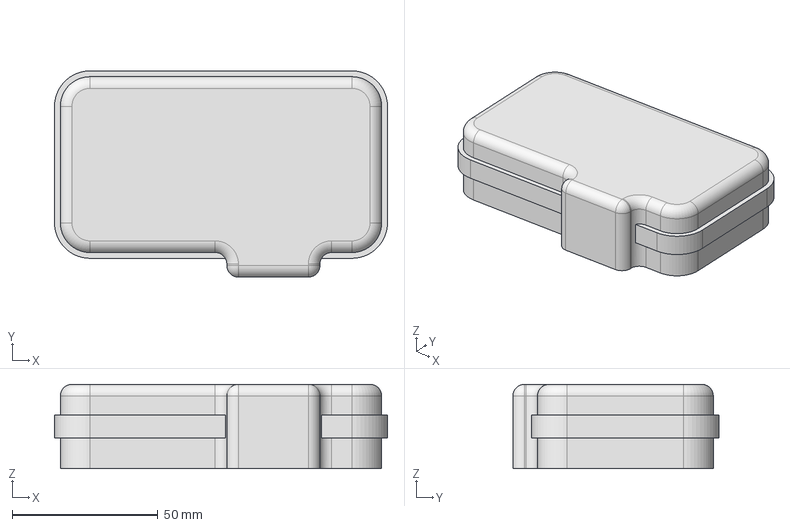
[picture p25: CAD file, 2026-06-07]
Hardware/Enclosure_Inventor_Project/Enclosure_Top.stp
114.4 x 70.9 x 29.0 mm

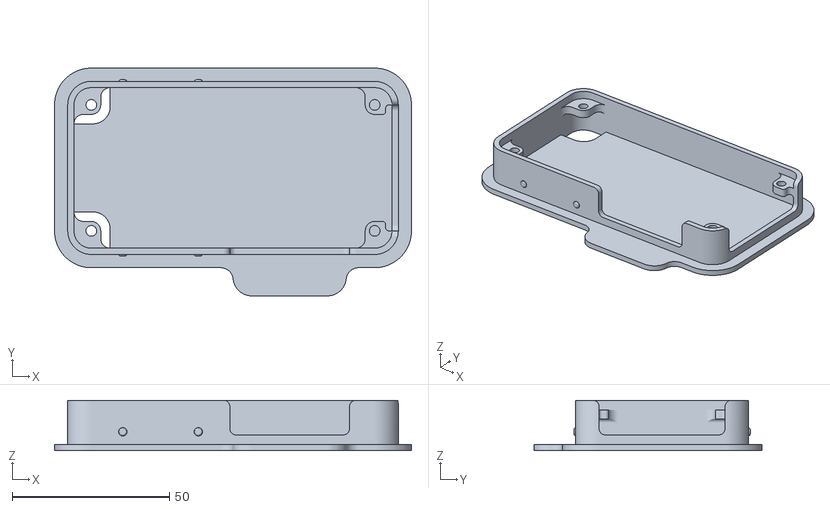
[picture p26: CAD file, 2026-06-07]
Production_Files/Enclosure STL Files/Enclosure Bottom.stl
113.4 x 72.4 x 16.0

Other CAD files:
Hardware/Enclosure_Inventor_Project/Enclosure Bottom.stp
Production_Files/Enclosure STL Files/Enclosure_Top.stl
Hardware/Enclosure_Inventor_Project/Enclosure Bottom.ipt
Hardware/Enclosure_Inventor_Project/Enclosure_Multibody.ipt
Hardware/Enclosure_Inventor_Project/Enclosure_Top.ipt
Hardware/Enclosure_Inventor_Project/OldVersions/Enclosure Bottom.0002.ipt
Hardware/Enclosure_Inventor_Project/OldVersions/Enclosure_Top.0003.ipt

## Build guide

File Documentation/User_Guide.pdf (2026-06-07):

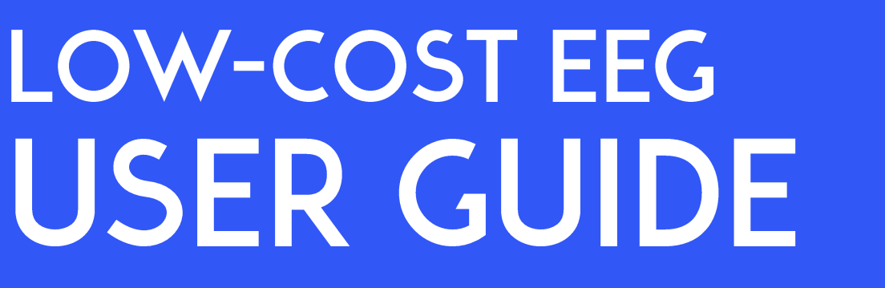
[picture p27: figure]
Low - Cost EEG User Guide

Supervisor: Dr Nic Zhang

## Xavier Asghar - MEng Final Project - 2025/26

01 | Overview | 3
02 Flashing the Module | 4
03 | Powering the Module | 8
04 | Applying the Electrodes | 10
05 | EEG BLE Receiver | 25
06 | Viewing & Recording Data | 33

# 1. Overview

This document contains the user guide for the Low-Cost EEG Module created as part of my University Final Year Project. The guide details how to setup and use the module for taking EEG measurements. The full details and design of the module can be found in the Final Report PDF.

In order to use the device, the procedure outlined below must be followed. Ensure the device in operated with battery power and the USB is disconnected at all times when connected to a subject. Each step is further explained in its respective section.

1. Ensure ESP32-S3 is flashed with the correct firmware. This includes specifying which channels will be in use to correctly derive the driven right leg bias signal.
2. Ensure USB is disconnected and the device is powered by a 3.7 V LiPo battery.
3. Prepare patient skin and apply electrodes.
4. Launch EEG_BLE_Receiver.exe (and press SW3 to take the board out of lead-off mode)
5. Launch Brainvision LSL Viewer to view EEG data in real time, or LabRecorder to record data to an XDF file.

Also contained in the repository are all the necessary production files (Gerbers, Schematic & Layout, BoM, STL files) to create your own module.

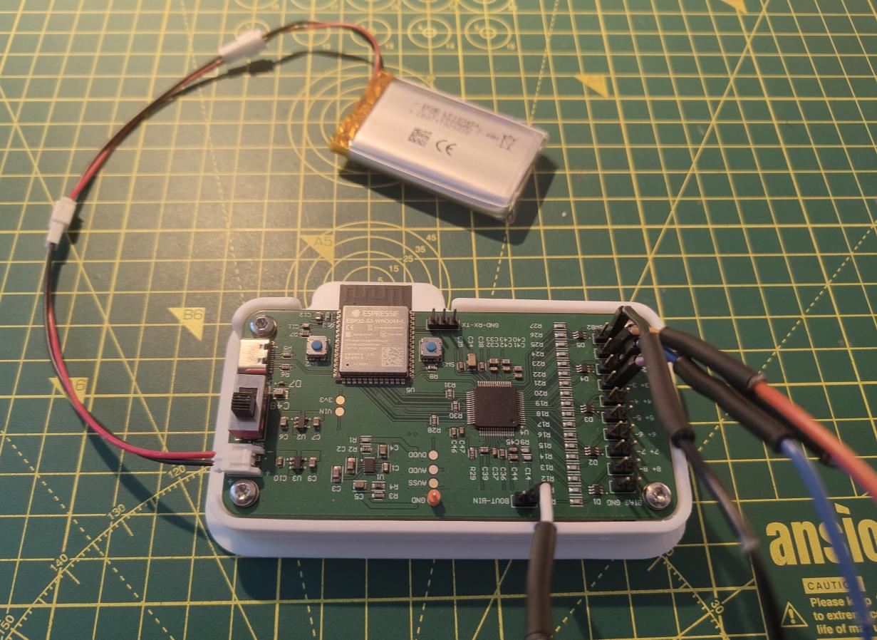
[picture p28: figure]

Figure 1: The complete EEG module

Before beginning EEG measurements the microcontroller must be running the correct code. This is especially important as the channels in use must be directly specified in the code to ensure the bias (driven right leg) signal is derived only from channels connected to the patient. The following steps outline how to correctly flash the module.

1. Install Visual Studio Code (VS Code).
2. Install the PlatformIO extenstion to VS Code.
3. In VS Code, open the Firmware_Platformio_Project folder, located in the software folder of the repository.
4. Wait for the project to finish configuring. This could take a few minutes.
5. Change the value of the BIAS_SENSP register, written to on line 102, in order to reflect the channels currently in use. The leftmost bit represents channel 8, while the rightmost bit represents channel 1. Channels in use should have a value of 1, while channels not in use should have a value of 0.

This ensures the driven right leg (bias) signal is only derived from channels connected to the subject. The example below shows the correct register value for when channels 1-3 are in use.

ADS.WREG(BIAS_SENSP, 0b00000111); // Derives bias from channels 1-3

6. Connect the module to the computer using the USB-C port, and upload the code, as shown in Figure 2. Ensure the correct COM port has been selected, and that the board power switch is set to USB power, as opposed to battery power.

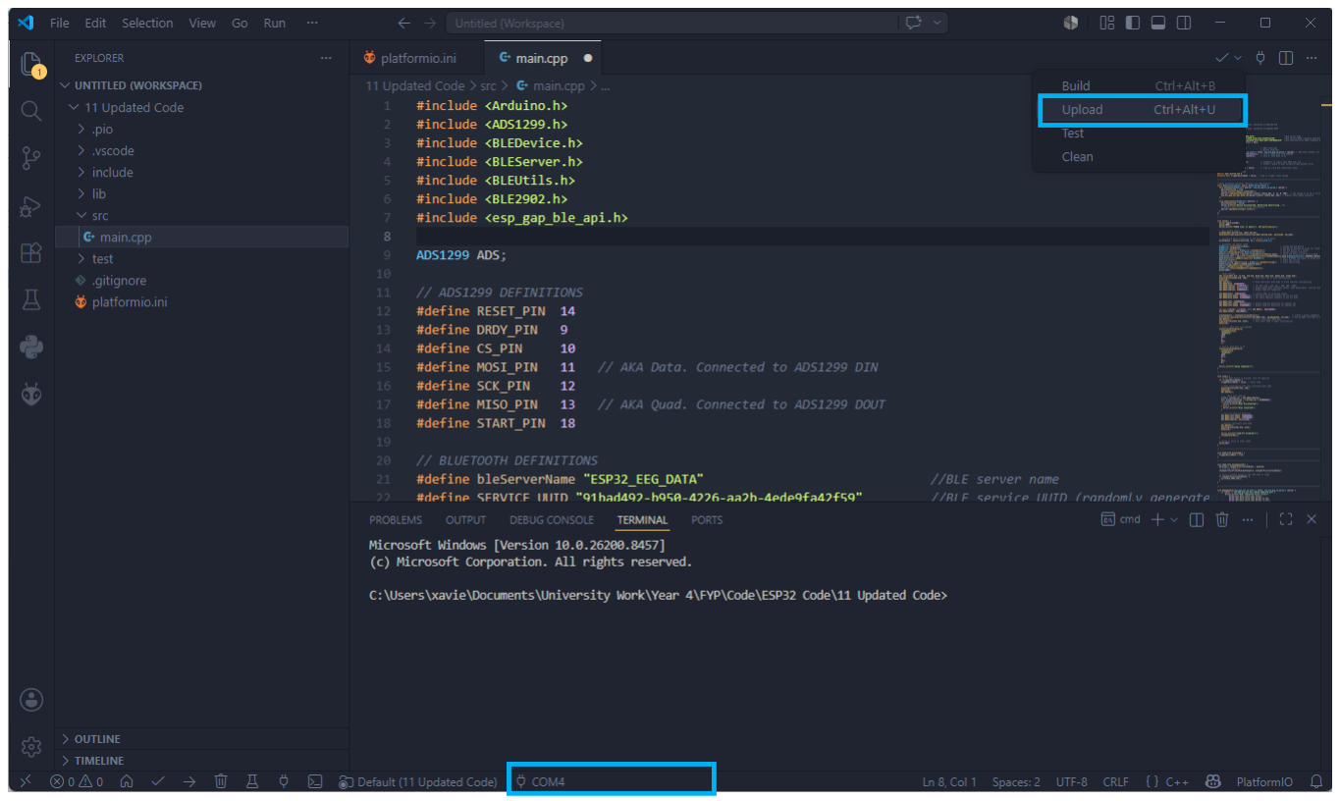
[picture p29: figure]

Figure 2: Platformio upload button

If the board is being flashed for the first time after assembly, the ESP32-S3 must be put into boot mode, using the following procedure:

- Press and hold the SW3 (BOOT) button
- Whilst continuing to hold SW3, press and release SW2 (RESET)
- Release SW3
- Upload code as shown in Figure 2.
- Press SW2

When connected to a subject, the board should be powered from a 3.7 V LiPo battery, connected to the 2-pin JST PH connector highlighted in Figure 3. Ensure the polarity of the battery wires matches the polarity shown on the silkscreen.

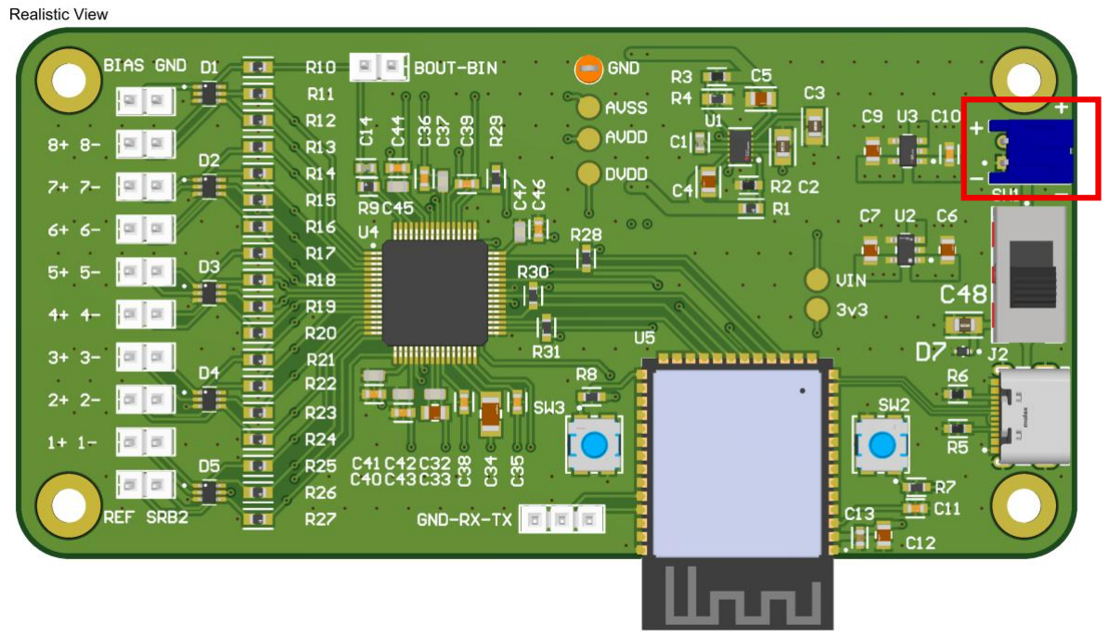
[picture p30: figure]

Figure 3: LiPo battery connector

During flashing, the board can be powered from a computer through the USB-C connector. Ensure that the USB-C cable is disconnected when the board is connected to a subject, to ensure electrical isolation of the subject from mains.

The switch (SW1) controls which power source is connected to the board, as well as acting as an on-off switch when the USB is not connected.

The module has been designed to be used with standard gold-cup electrodes. As shown in Figure 4, the active electrodes should be attatched to the positive pin headers (Pins 8+, 7+, … , 1+), while the bias and reference electrodes should be attatched to the BIAS and REF pins respectively.

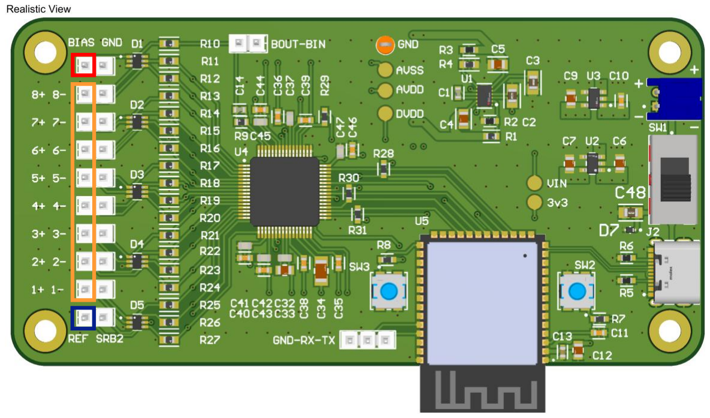
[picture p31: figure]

Figure 4: Electrode Connections

The active electrodes should be applied to the patient at locations set out by the international 10-20 system, while the reference and bias should typically be placed at electrically neutral locations, for instance the left and right mastoid, or the left and right earlobe. When applying electrodes to the patient, the following procedure should be adhered to:

1. Skin at electrode locations wiped with 70% Isopropyl Alcohol (IPA) wipes to remove oil and sweat.
2. The same locations rubbed with woven gauze swabs to remove dead skin cells, dirt, and residual IPA.
3. Electrode cups filled with Ten20 conductive paste to form a slight dome, such that when applied to the patient, some paste is pushed out from underneath the electrode.
4. Electrodes affixed to target locations. In hairless areas this can be done using medical tape. For areas containing hair, use tubular bandage, a headband, or a skull cap to maintain pressure on the electrodes.
5. Electrode wires taped to the patient (typically to the neck) with sufficient slack to prevent mechanical pulling and provide strain relief.

Alternatively, the IPA wipes and gauze can be replaced with NuPrep abrasive gel. The following guide can be used as reference for the application process: https://www.youtube.com/watch?v=b26vNbk8TOc

If gold-cup electrodes with female Dupont style terminations
cannot be sourced, it is possible to purchase electrodes with standard EEG touchproof connectors, which can then be cut-off, and replaced with Dupont style connectors, as shown in Figure 5. Here the resulting solderjoint has been covered with heatshrink.

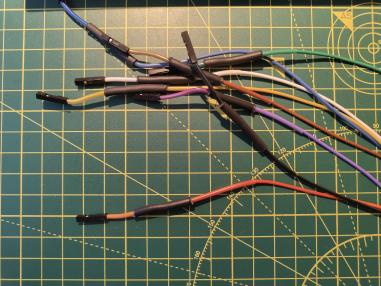
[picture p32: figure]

Figure 5: Electrode leads soldered to female Dupont wires

In order to receive the EEG data being sent over bluetooth by the ESP32, and to subsequently push that data to the Lab Streaming Layer, the EEG_BLE_Receiver.EXE must be launched. Ensure that the computer/laptop running the application has Bluetooth enabled.

The application, shown in Figure 6, will scan for the ESP32, and once connected the following information is displayed on the console:

- Dropped packets: Counts the number of data packets that have been missed from the ADS1299. This counter should remain at 0 (however if the firmware is altered, and the ADS1299 is set to stream data at above 500 SPS, packets may be dropped).
- Queue depth: This should remain close to 0. If this number continually increases, it means that data is being read over bluetooth faster than it is being unpacked and pushed to the LSL.
- Lead-Off bits: These indicate the quality of the electrode connection for each channel. When in Lead-Off mode, a 0 indicates the electrode has a good connection, while a 1 indicates the electrode has a poor connection.
- Channel voltages: Displays the current voltage of each channel every 100 ms. This is to verify the system is working, rather than to be used as a way of reading EEG data.

Figure 6: EEG_BLE_Receiver application

Upon reset, the EEG module starts in Lead-Off mode. This is where a small DC current is injected into each of the electrode inputs, and a voltage measured to determine if the electrode is on or off. This current can interfere with the EEG measurements, and thus once the electrode connections have been verified, the SW3 button must be pressed to exit Lead-Off mode.

With the EEG_BLE_Receiver application running, the EEG data is now being pushed to the Lab Streaming Layer, where multiple free to use applications can be used to view and record the EEG data.

The most straightforward application to view the EEG data in real time is BrainVision LSL Viewer, which can be downloaded from the Brain Products website. (https://www.brainproducts.com/downloads/more-software/#lsl) This application, shown in Figure 7, also lets you filter the EEG data, as well as view the FFTs for each channel. When viewing EEG data, I recommend using a mains frequency notch filter to remove power line interference, as well as a 0.5 – 150 Hz bandpass filter to remove noise.

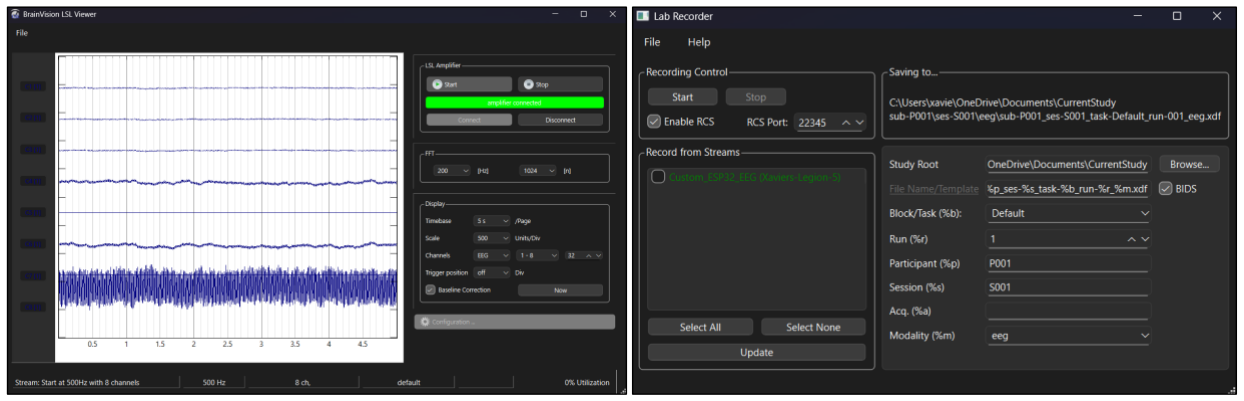
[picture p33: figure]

Figure 7.1: BrainVision LSL Viewer | Figure 7.2: LabRecorder

Additionally, EEG data can be recorded using the LabRecorder application, (https://github.com/labstreaminglayer/App-LabRecorder) shown in Figure
7.2. This allows for the concurrent recording of multiple LSL streams, which is useful for linking external stimuli to their respective EEG responses, through the use of LSL marker streams. The EEG data is recorded into an XDF file, which can then be opened in python using the PyXDF library.

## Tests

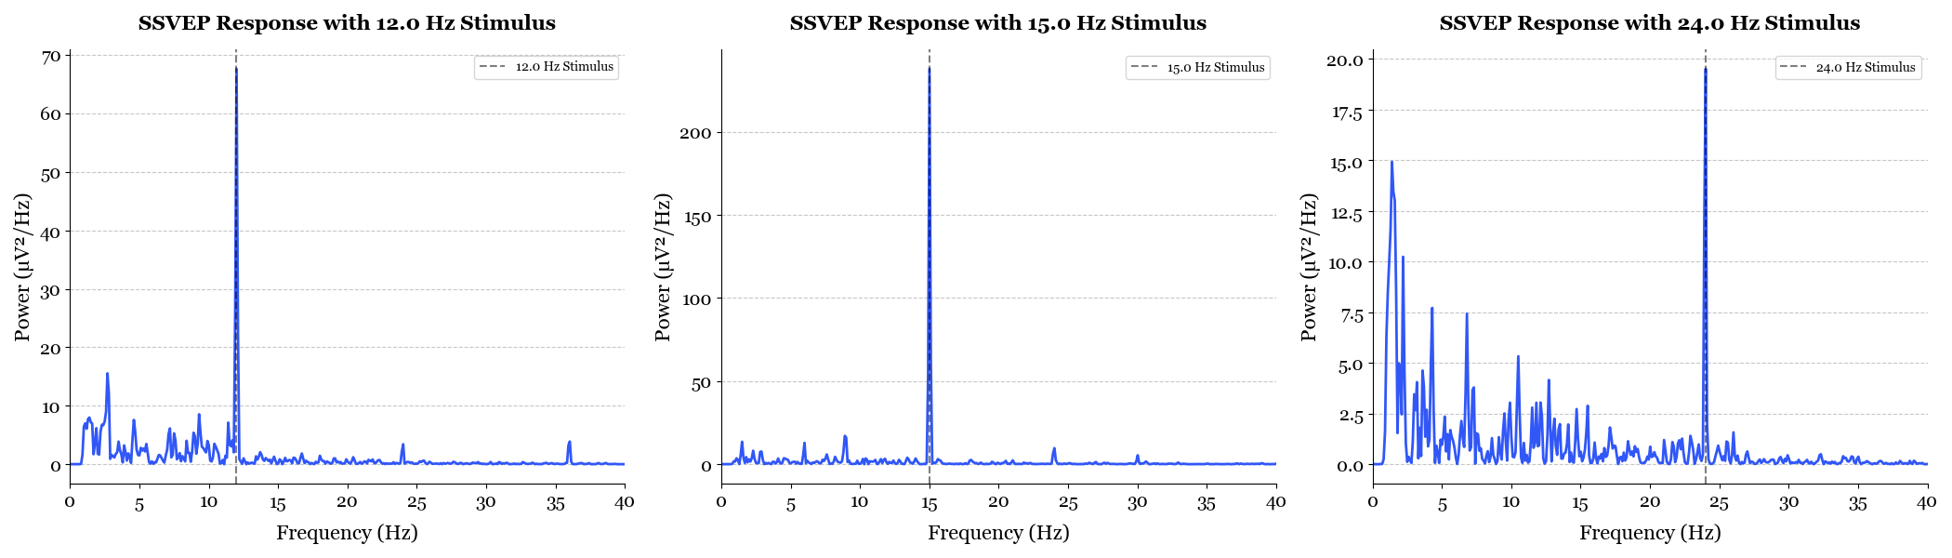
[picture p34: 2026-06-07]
Software/EEG Test Scripts/Example Results/SSVEPs.png

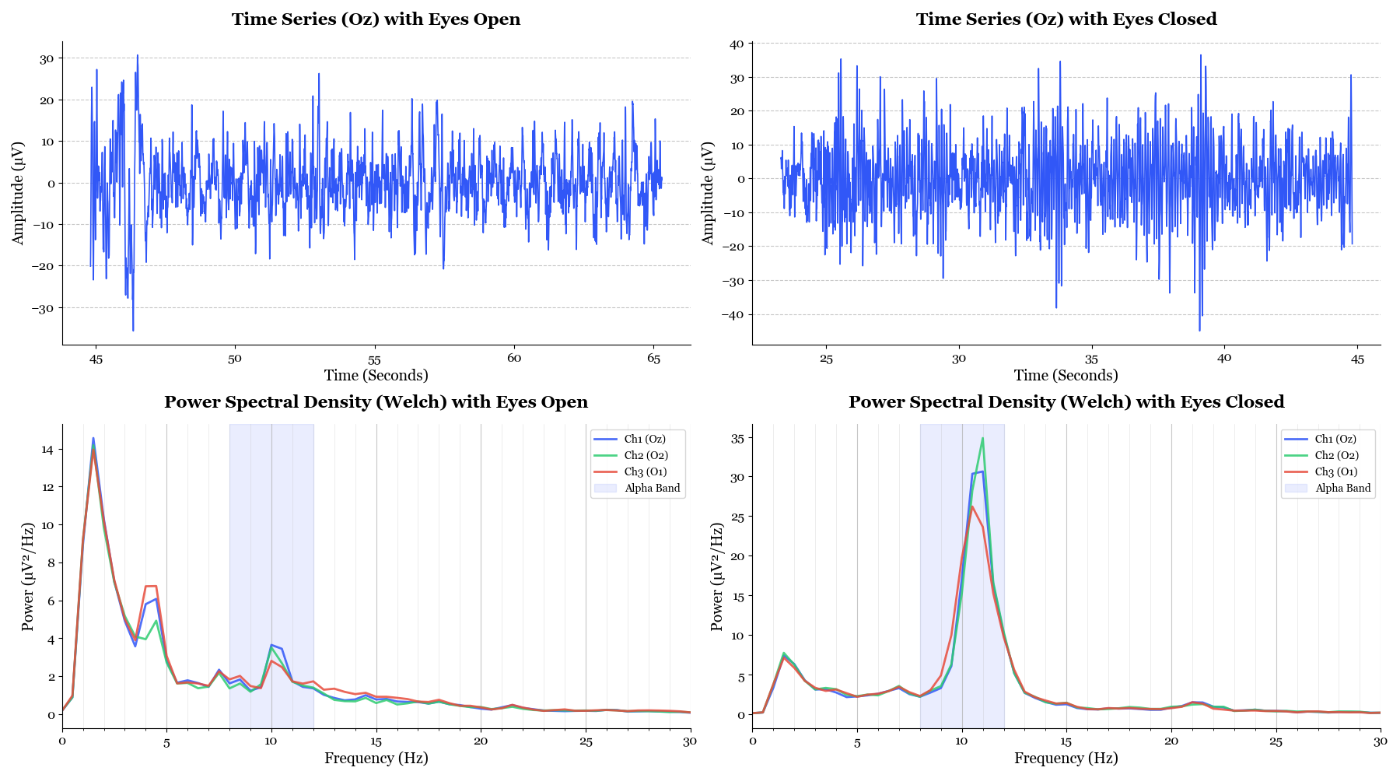
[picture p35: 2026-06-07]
Software/EEG Test Scripts/Example Results/Alpha Waves.png

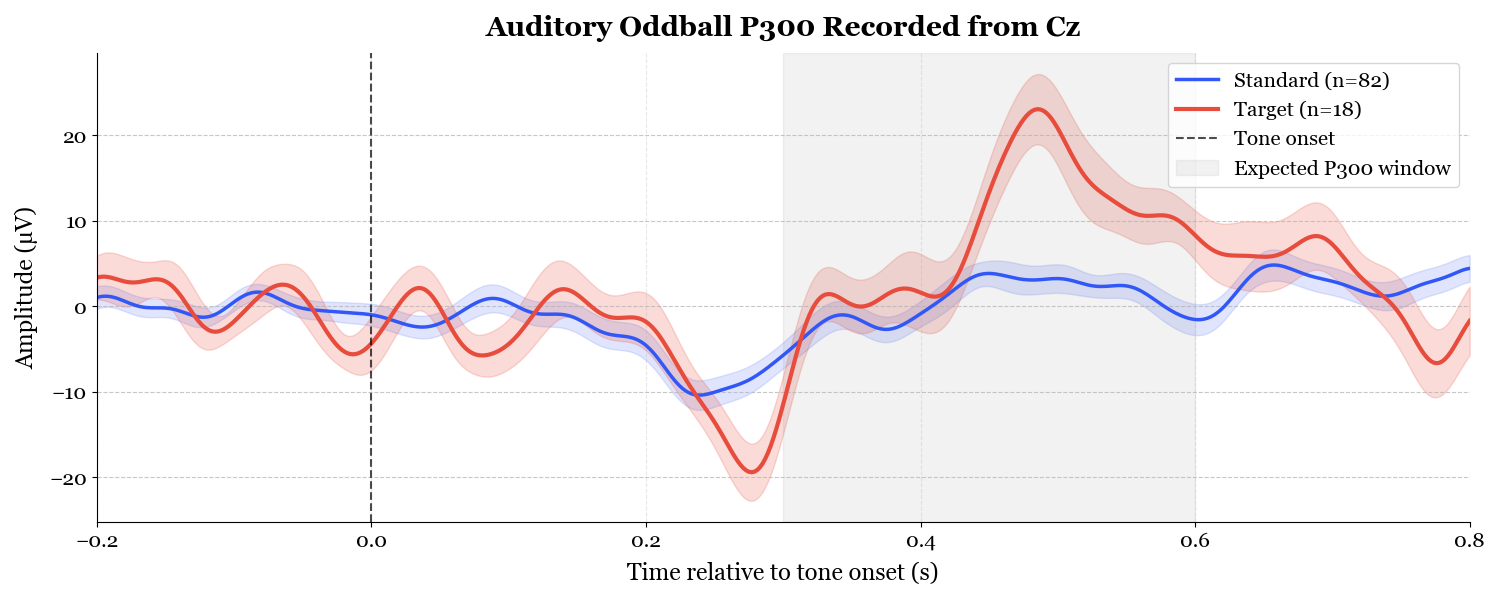
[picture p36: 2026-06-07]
Software/EEG Test Scripts/Example Results/P300 Average.png

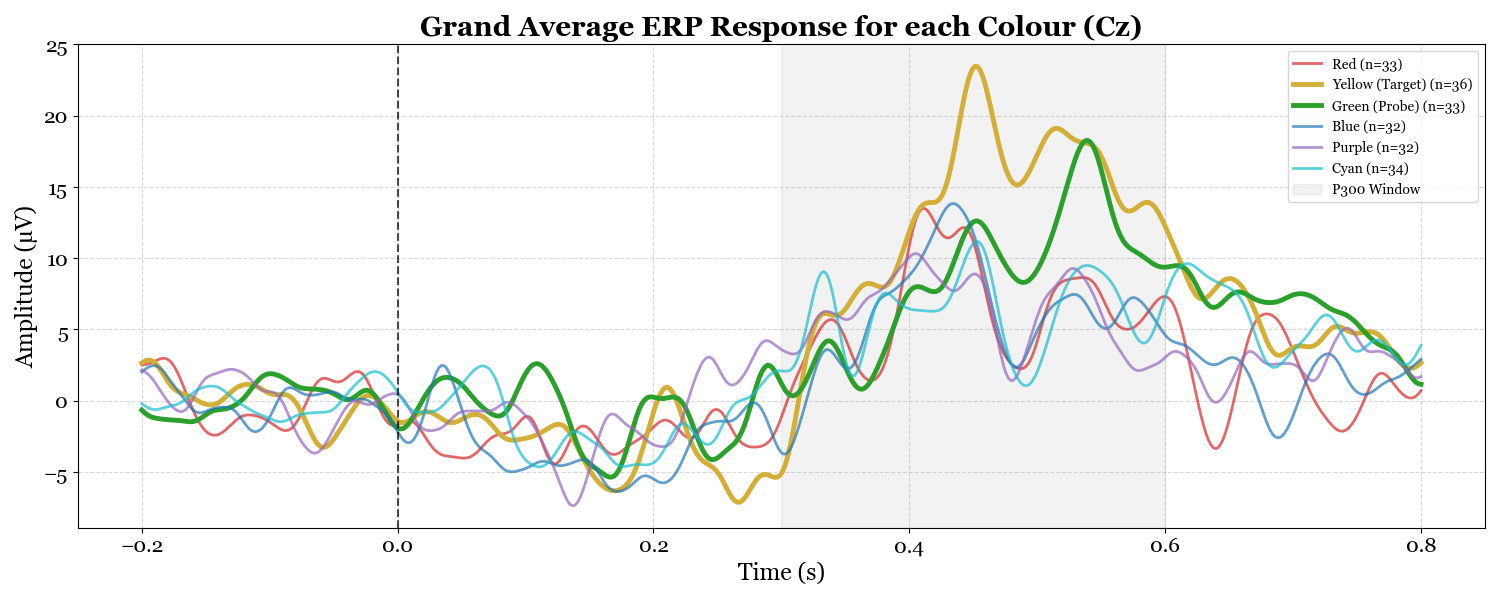
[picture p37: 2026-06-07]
Software/EEG Test Scripts/Example Results/Lie Detector Average.png

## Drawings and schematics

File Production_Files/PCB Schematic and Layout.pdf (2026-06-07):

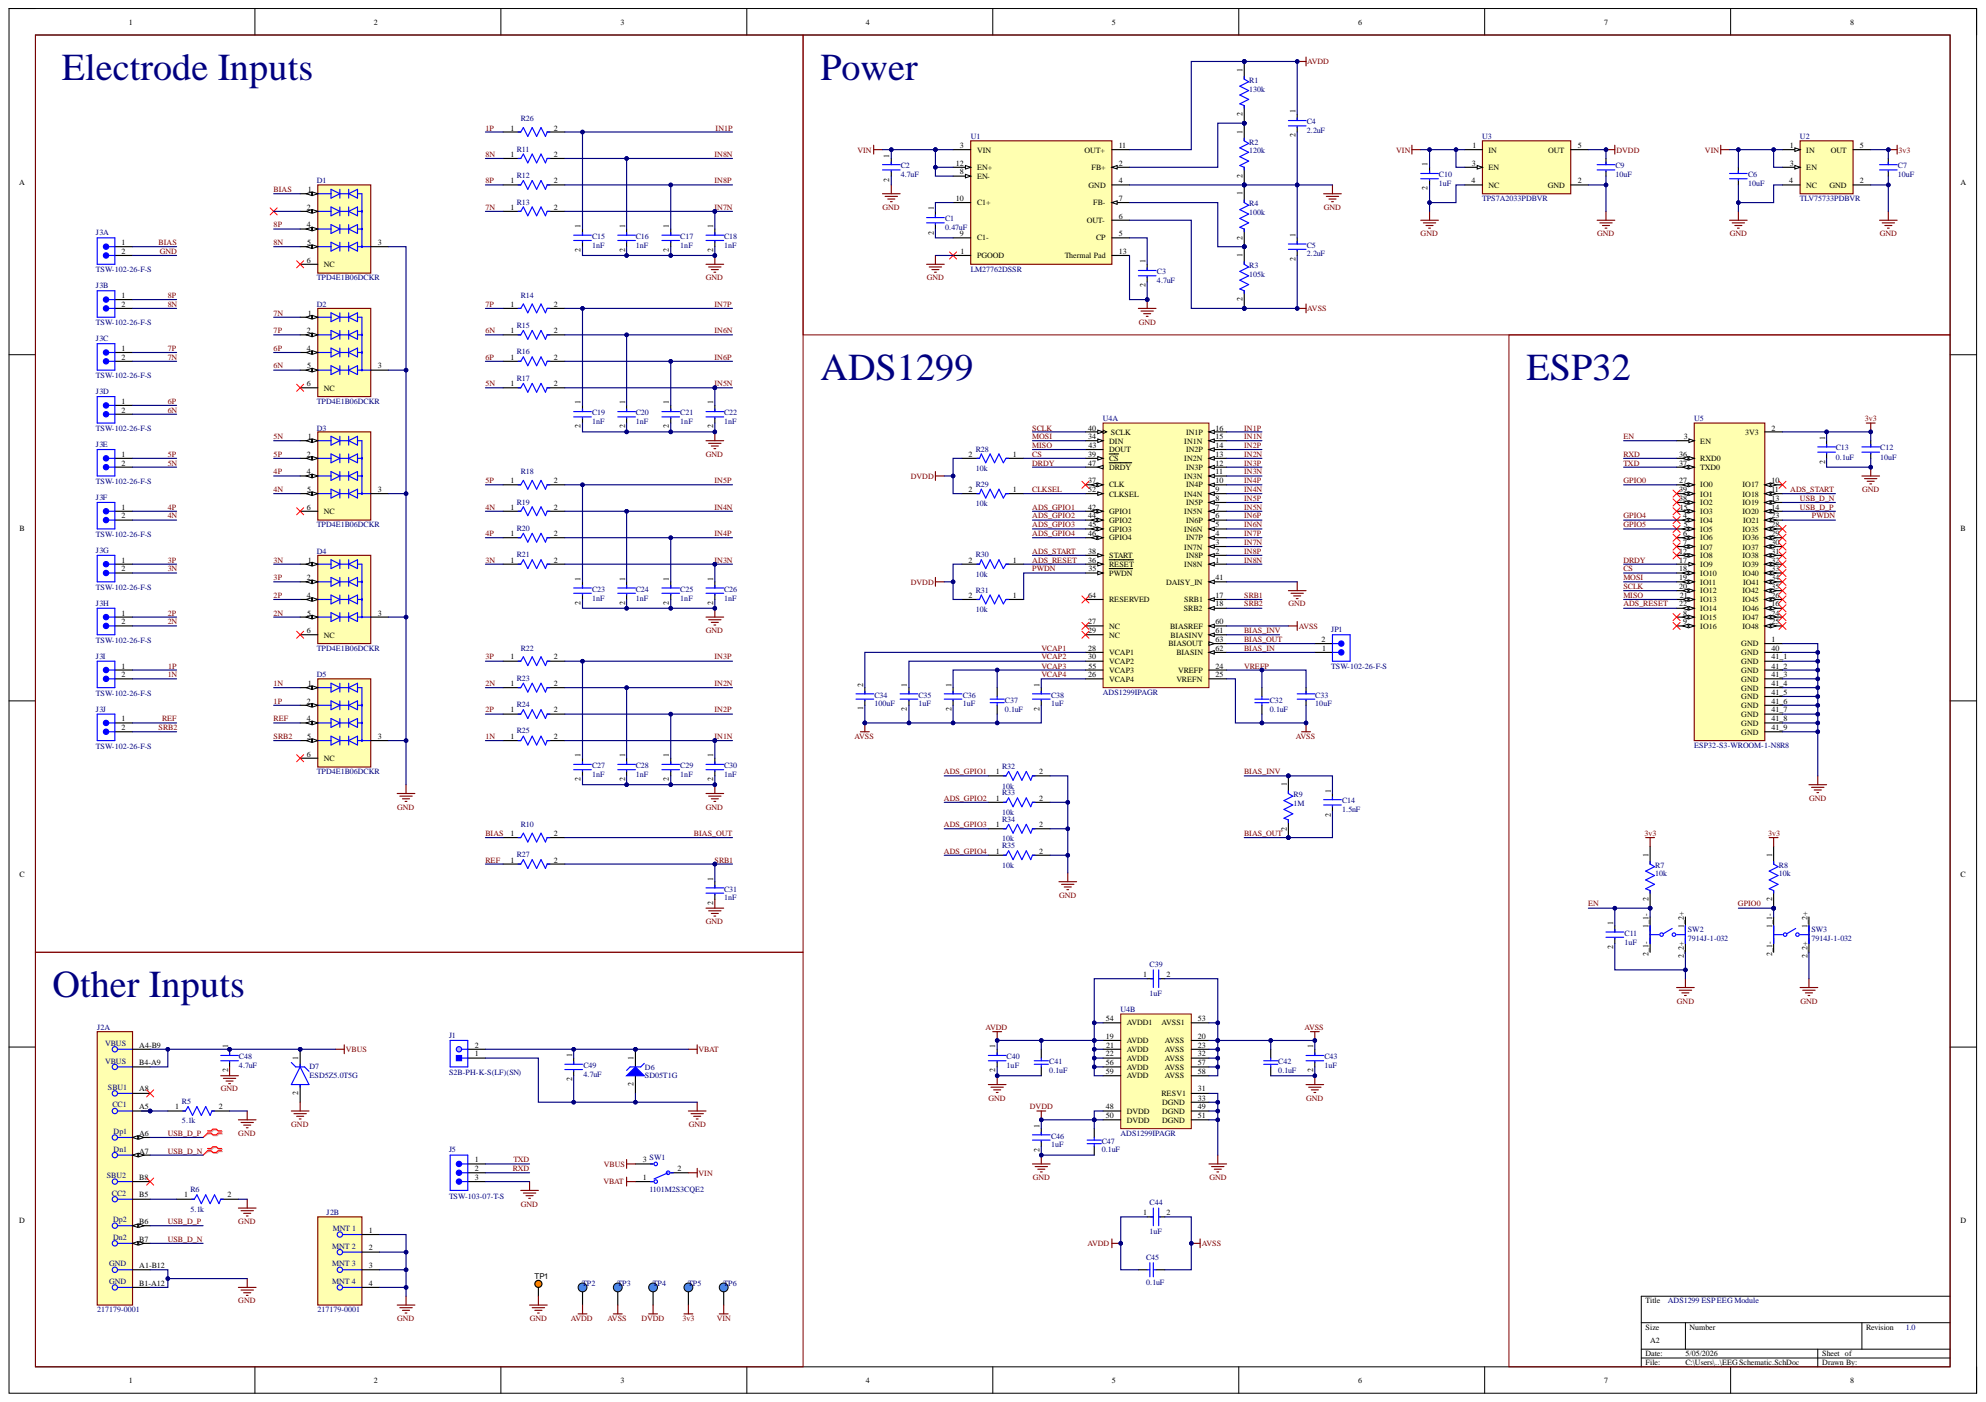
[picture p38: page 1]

DRDY CSMOSI SCLK MISO

A2 | r | R evision 1. 0

Date : 5/05/2026 | She et of
File : C:\Us e r s\. .\E EG S chematic . S chDoc | Dr awn By:

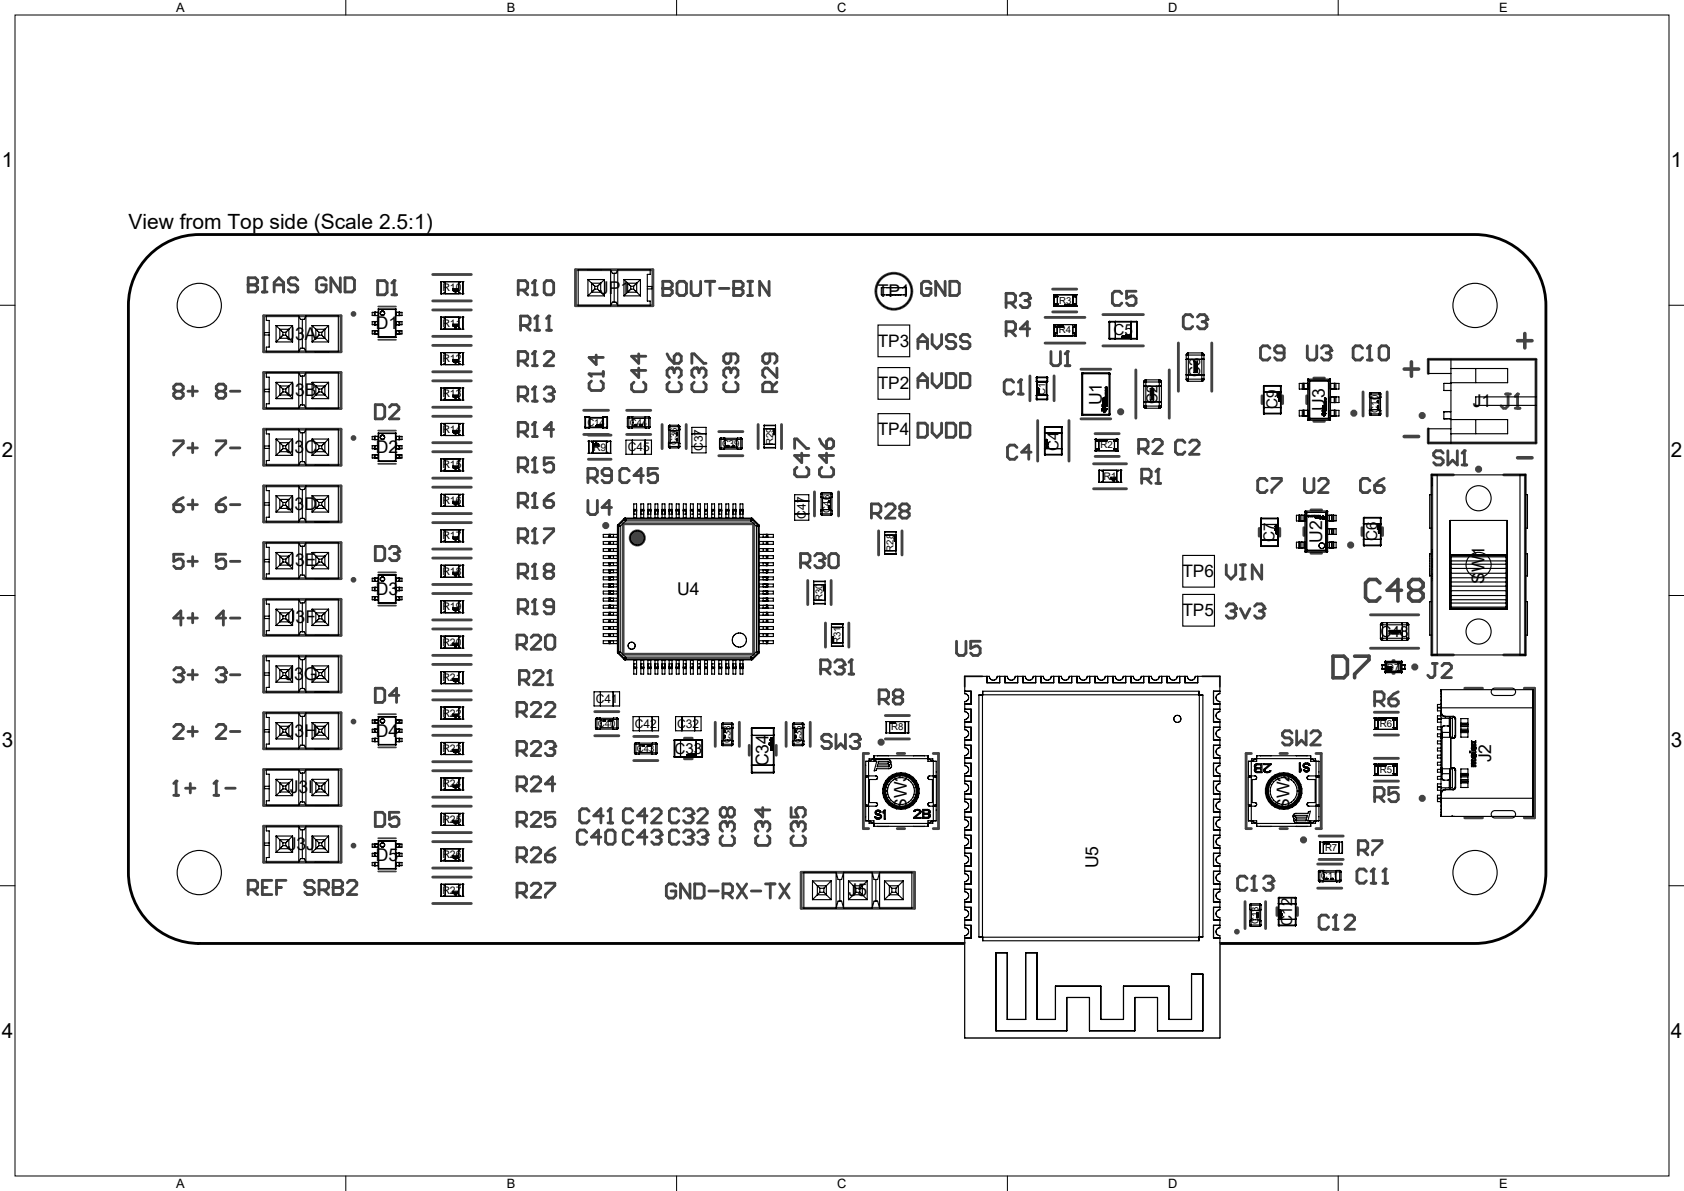
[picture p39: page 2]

View from Top side (Scale 2.5:1)

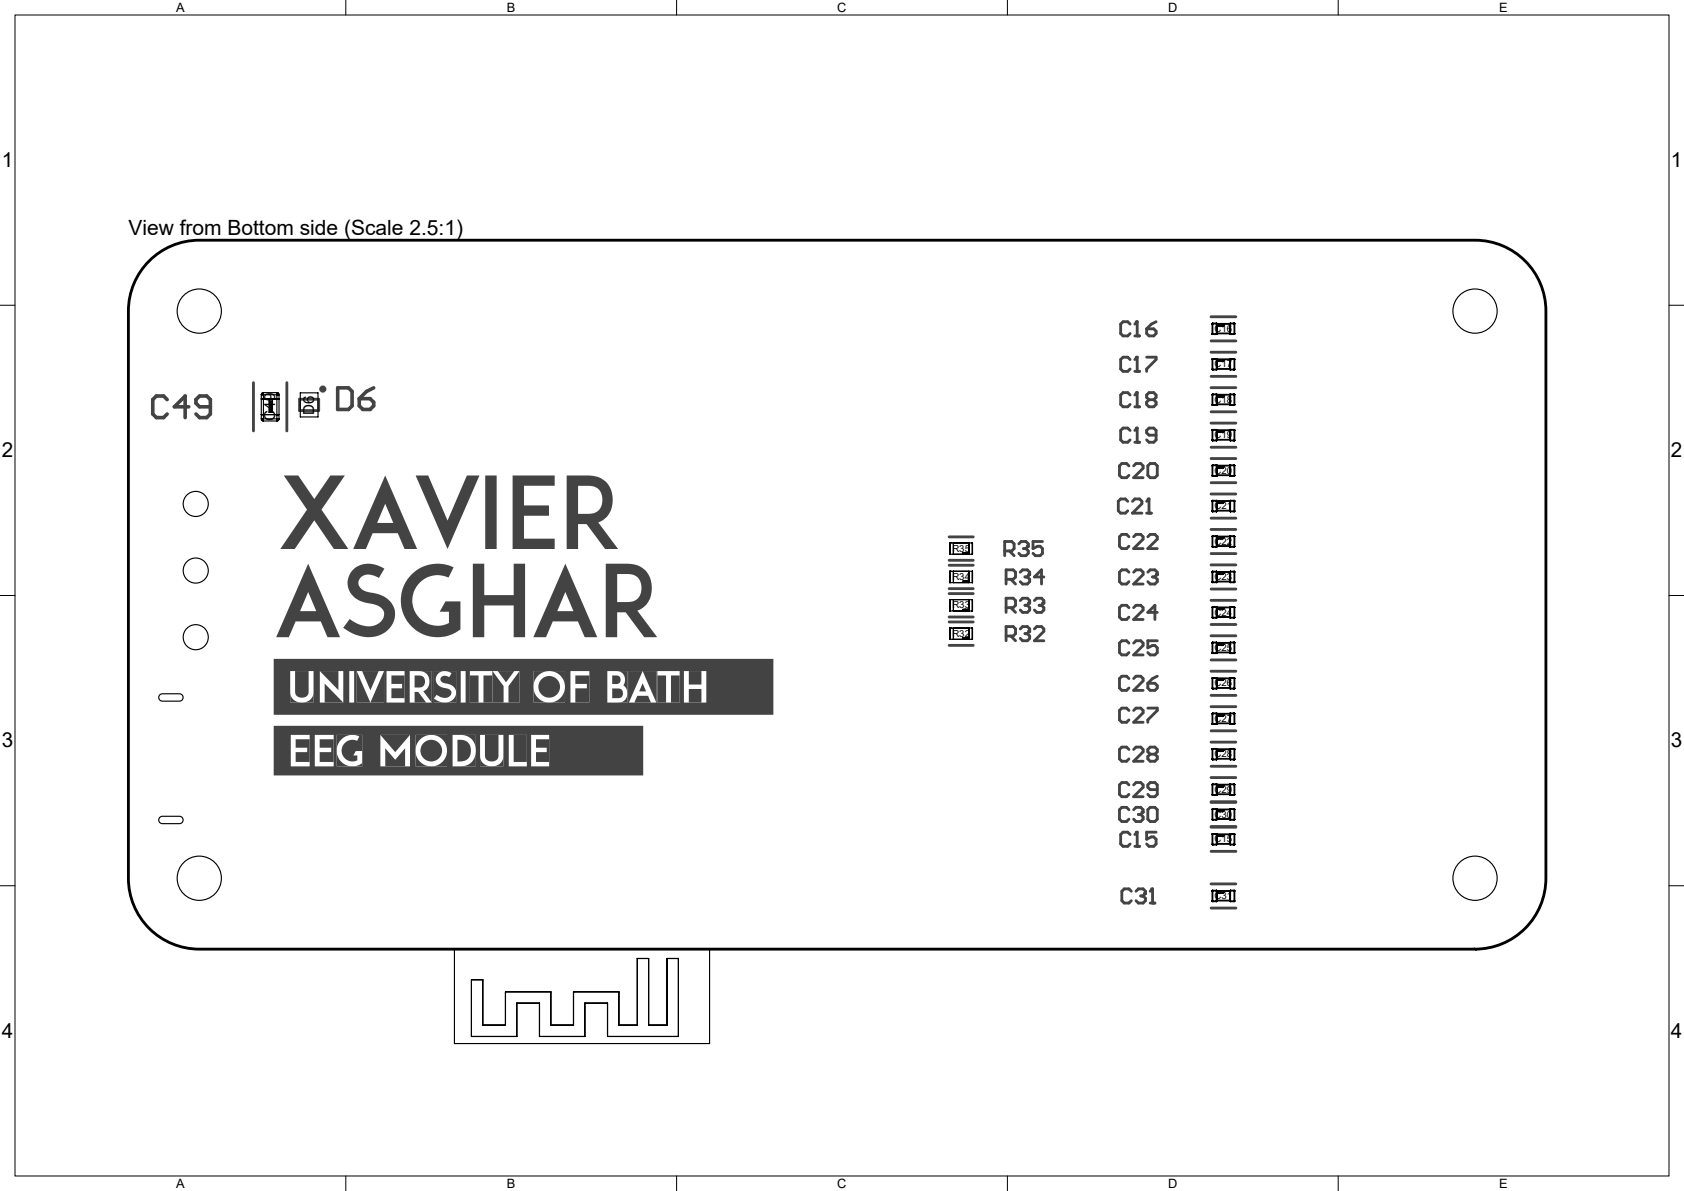
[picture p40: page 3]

View from Bottom side (Scale 2.5:1)

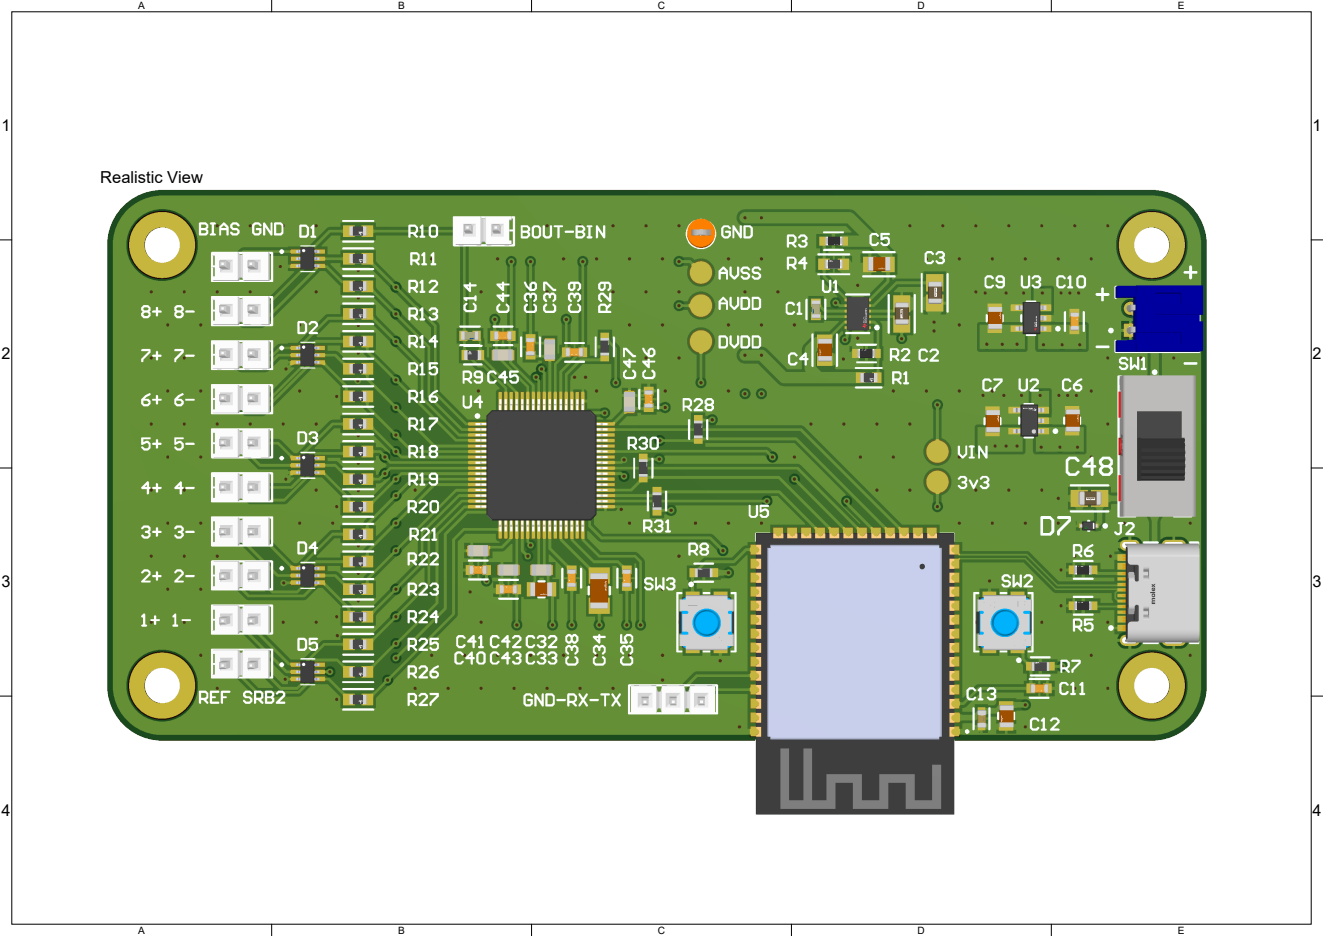
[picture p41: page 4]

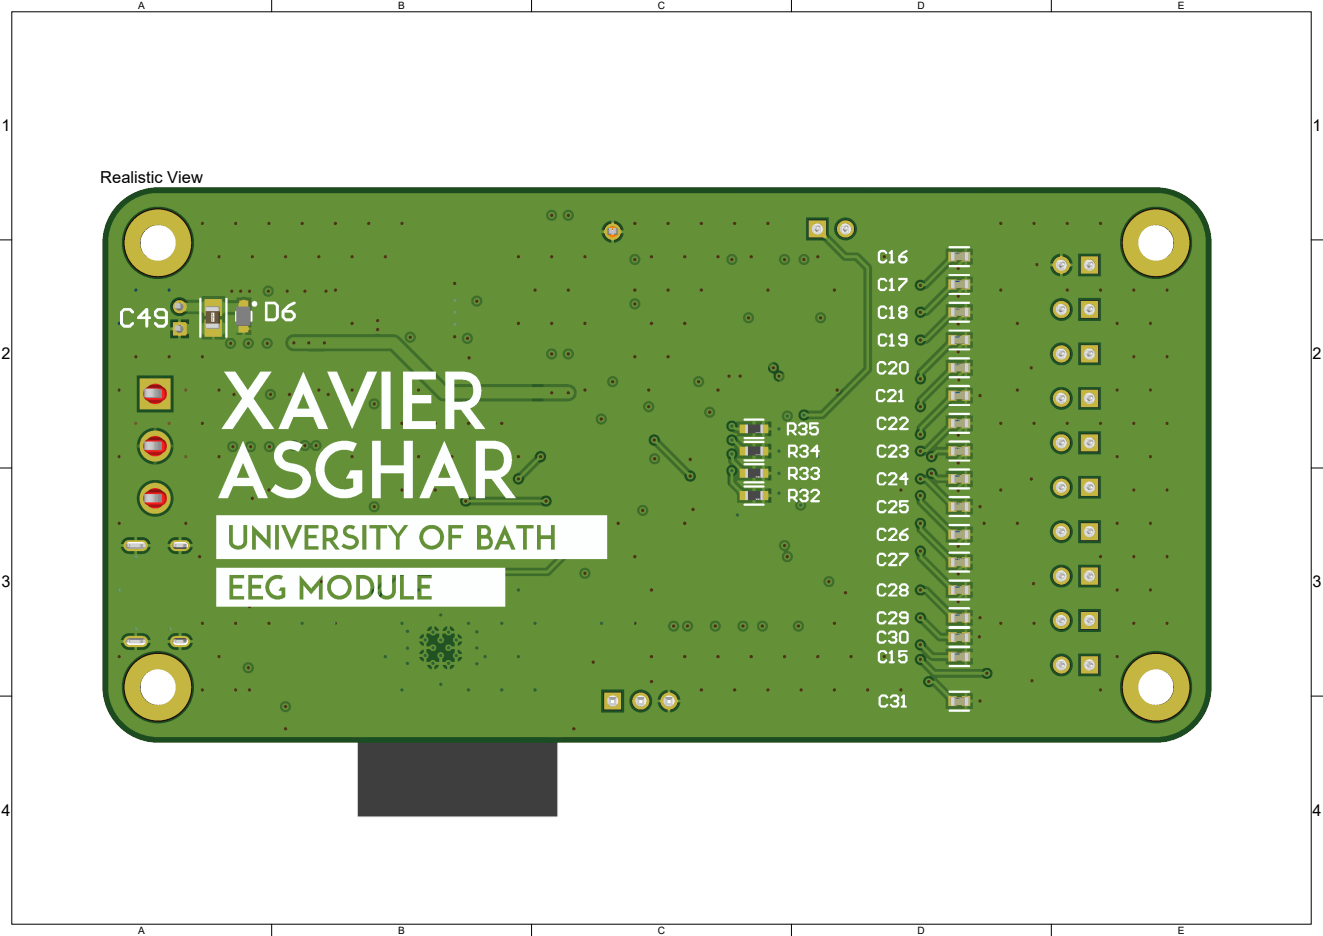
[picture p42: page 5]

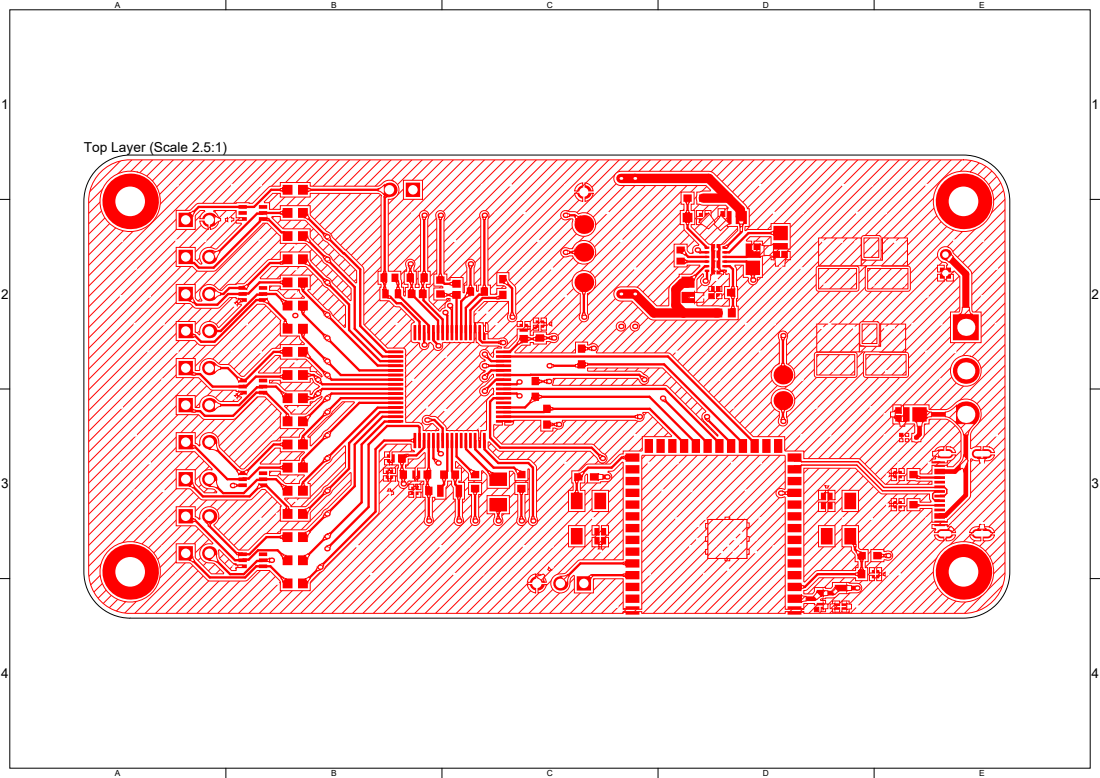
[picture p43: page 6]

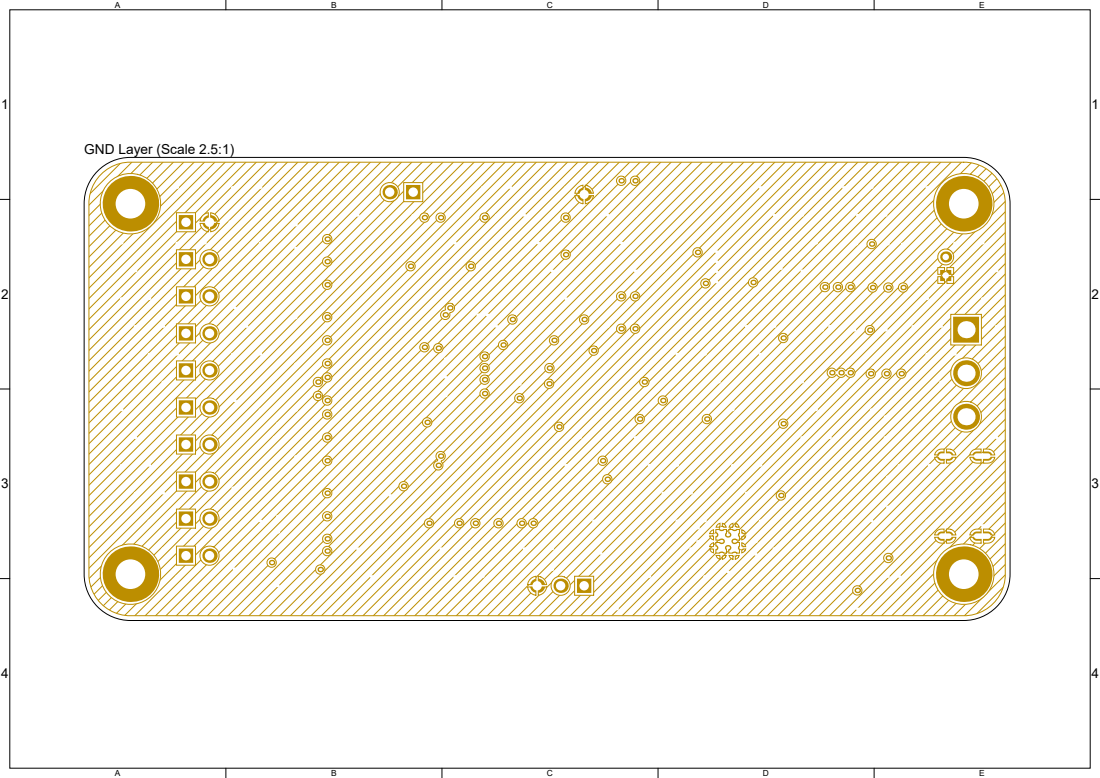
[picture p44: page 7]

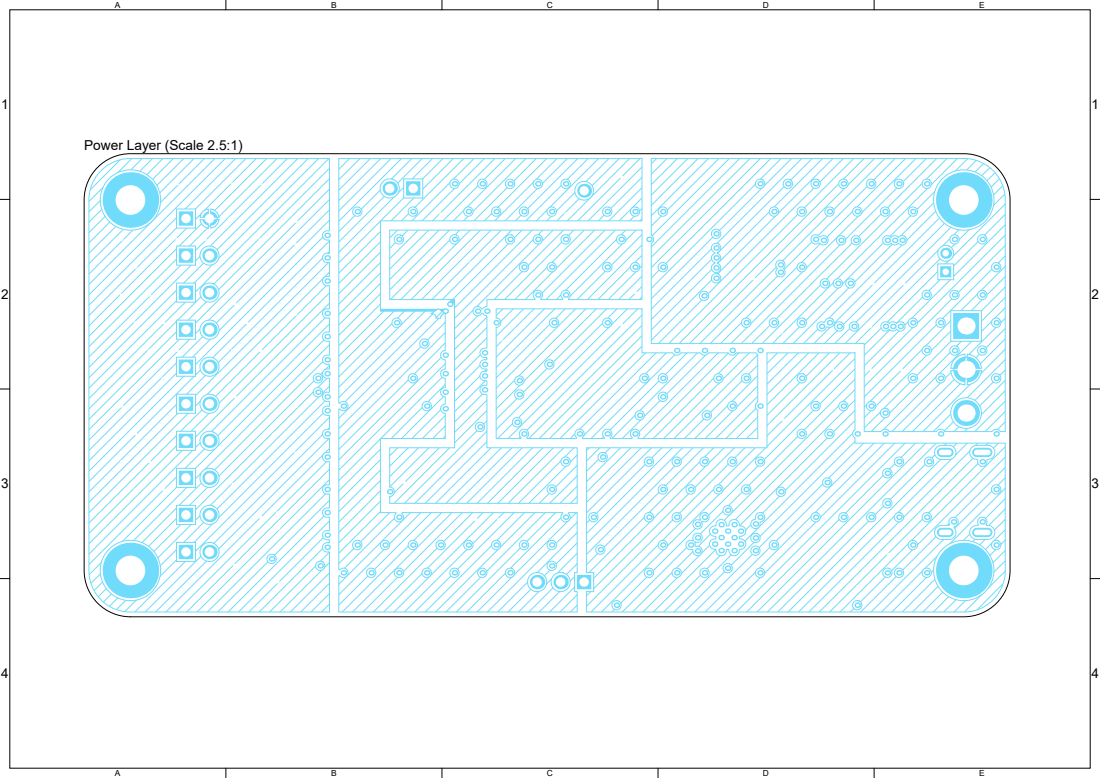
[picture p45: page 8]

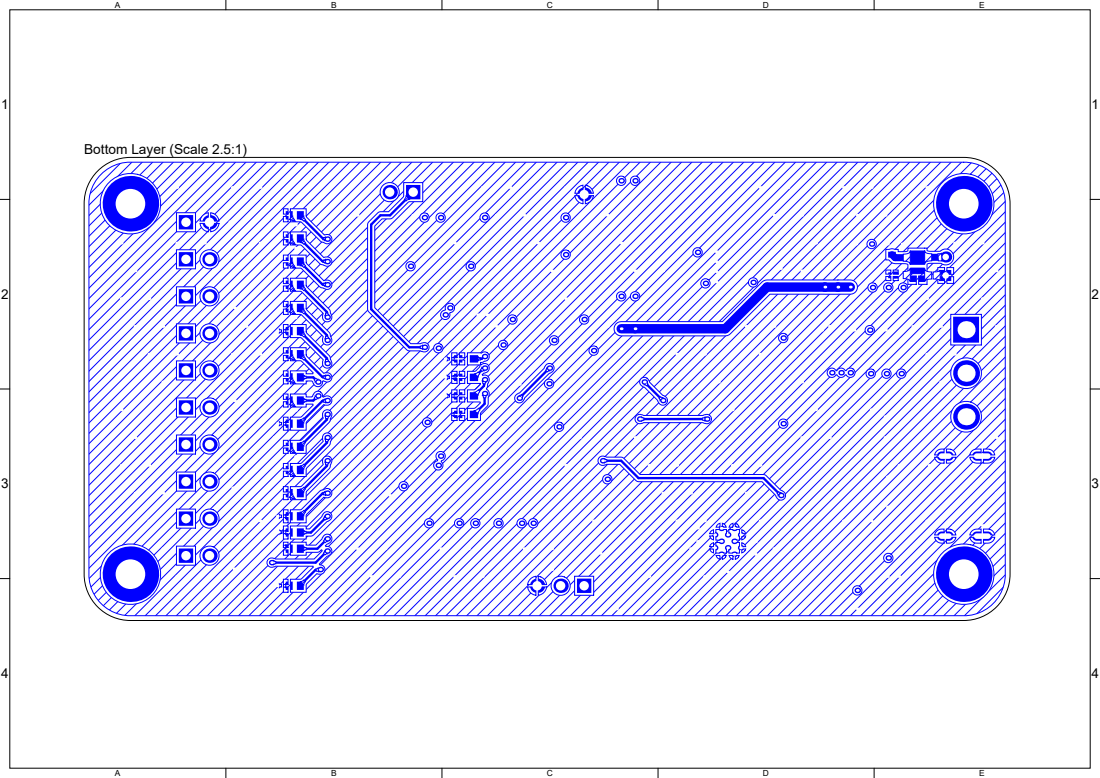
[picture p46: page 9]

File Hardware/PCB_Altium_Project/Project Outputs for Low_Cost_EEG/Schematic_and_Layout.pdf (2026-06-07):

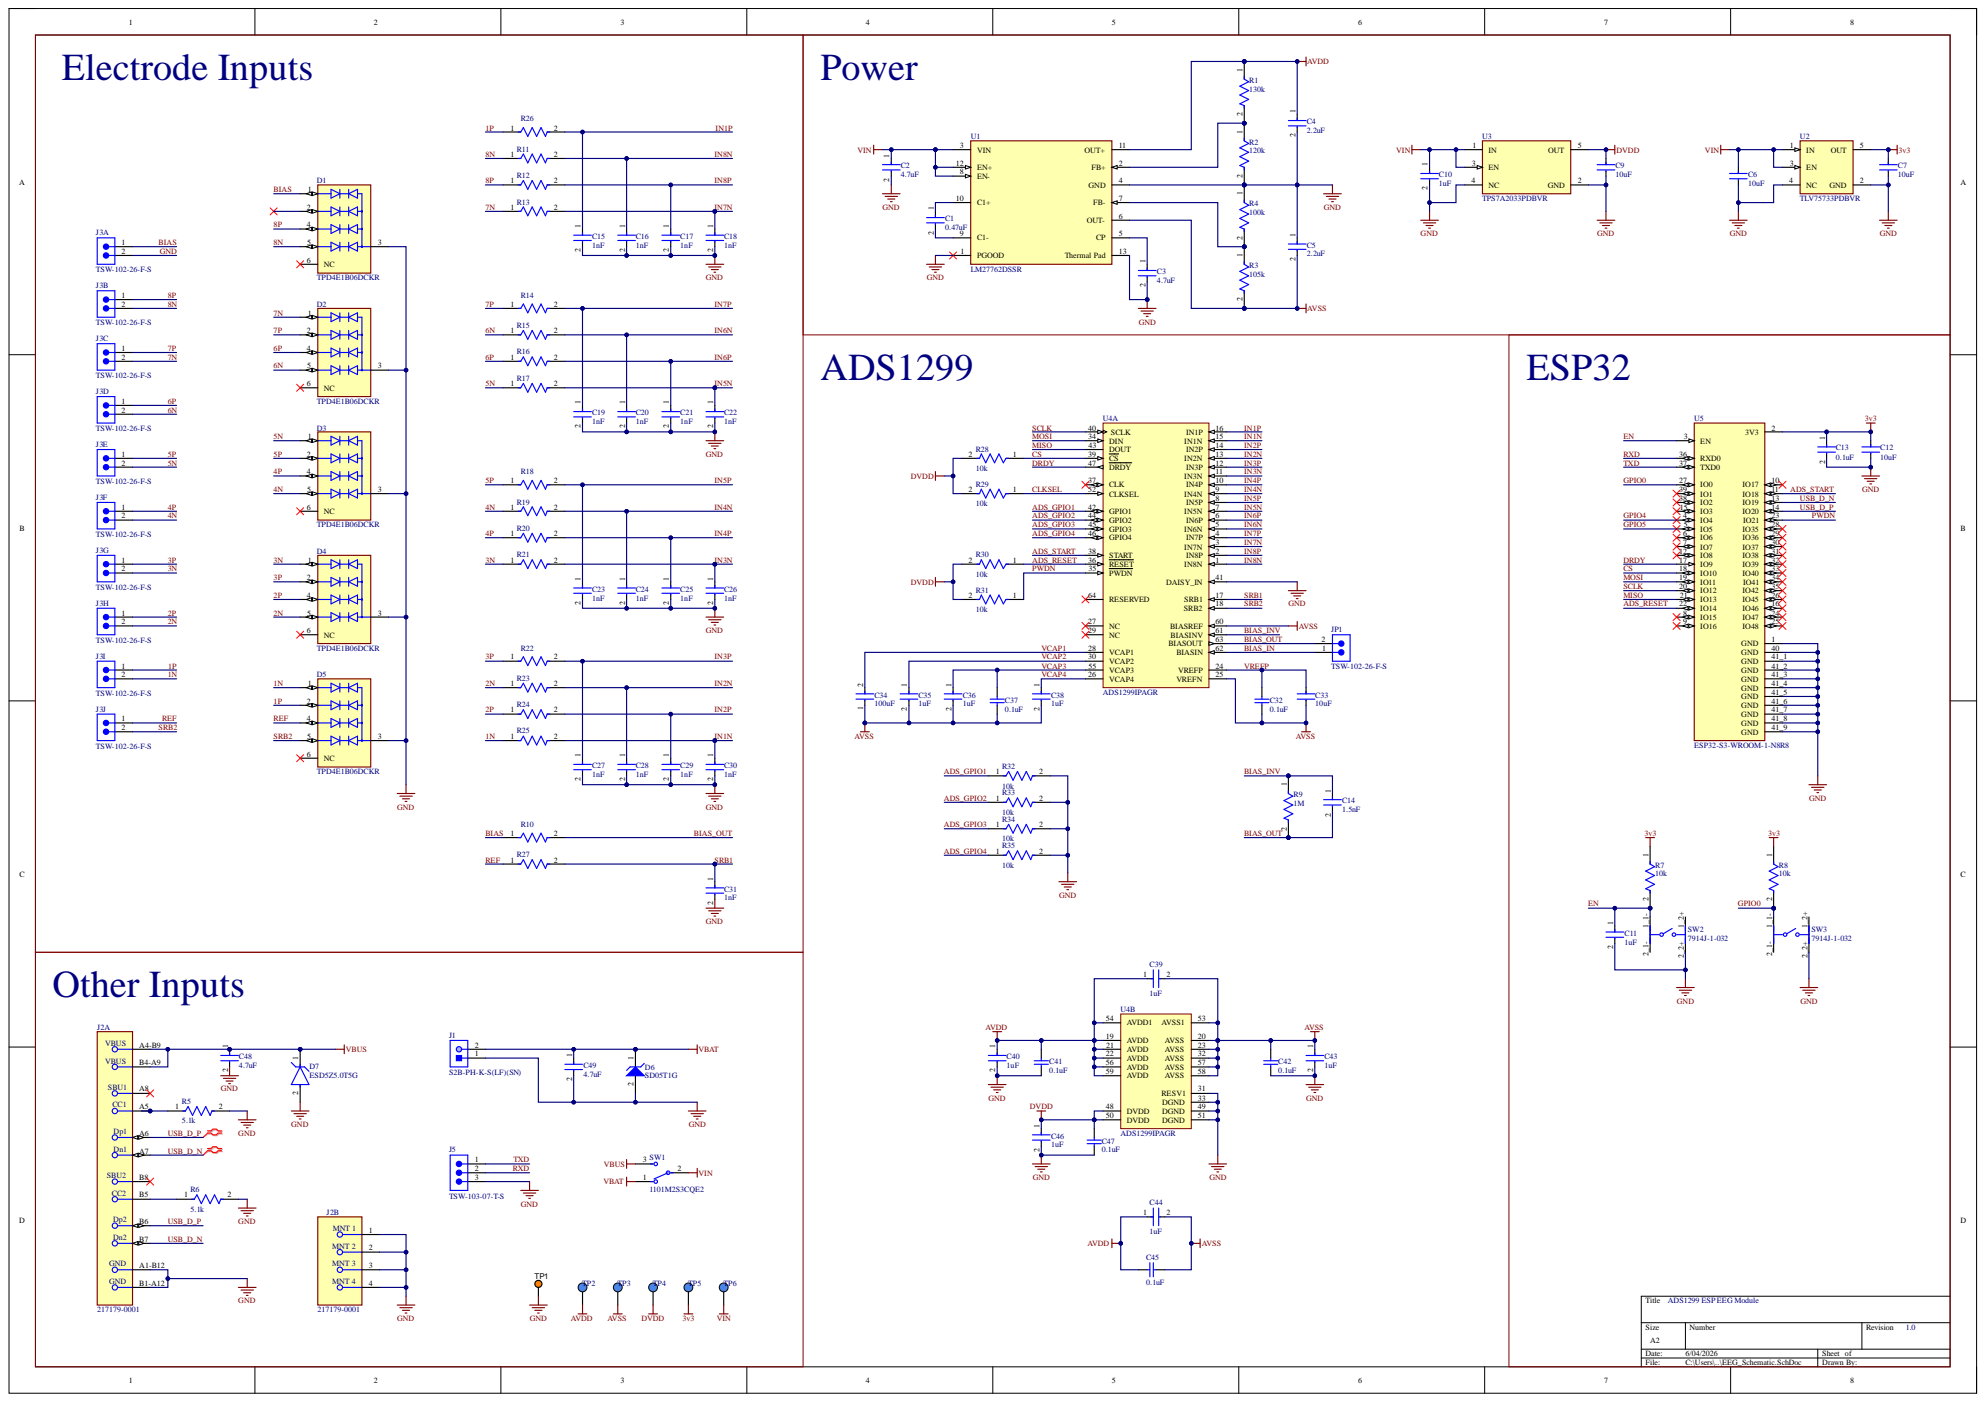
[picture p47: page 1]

DRDY CSMOSI SCLK MISO

A2 | r | R evision 1. 0

Date : 6/04/2026 | She et of
File : C:\Us e r s\. .\E EG_S chematic . S chDo c | Dr awn By:

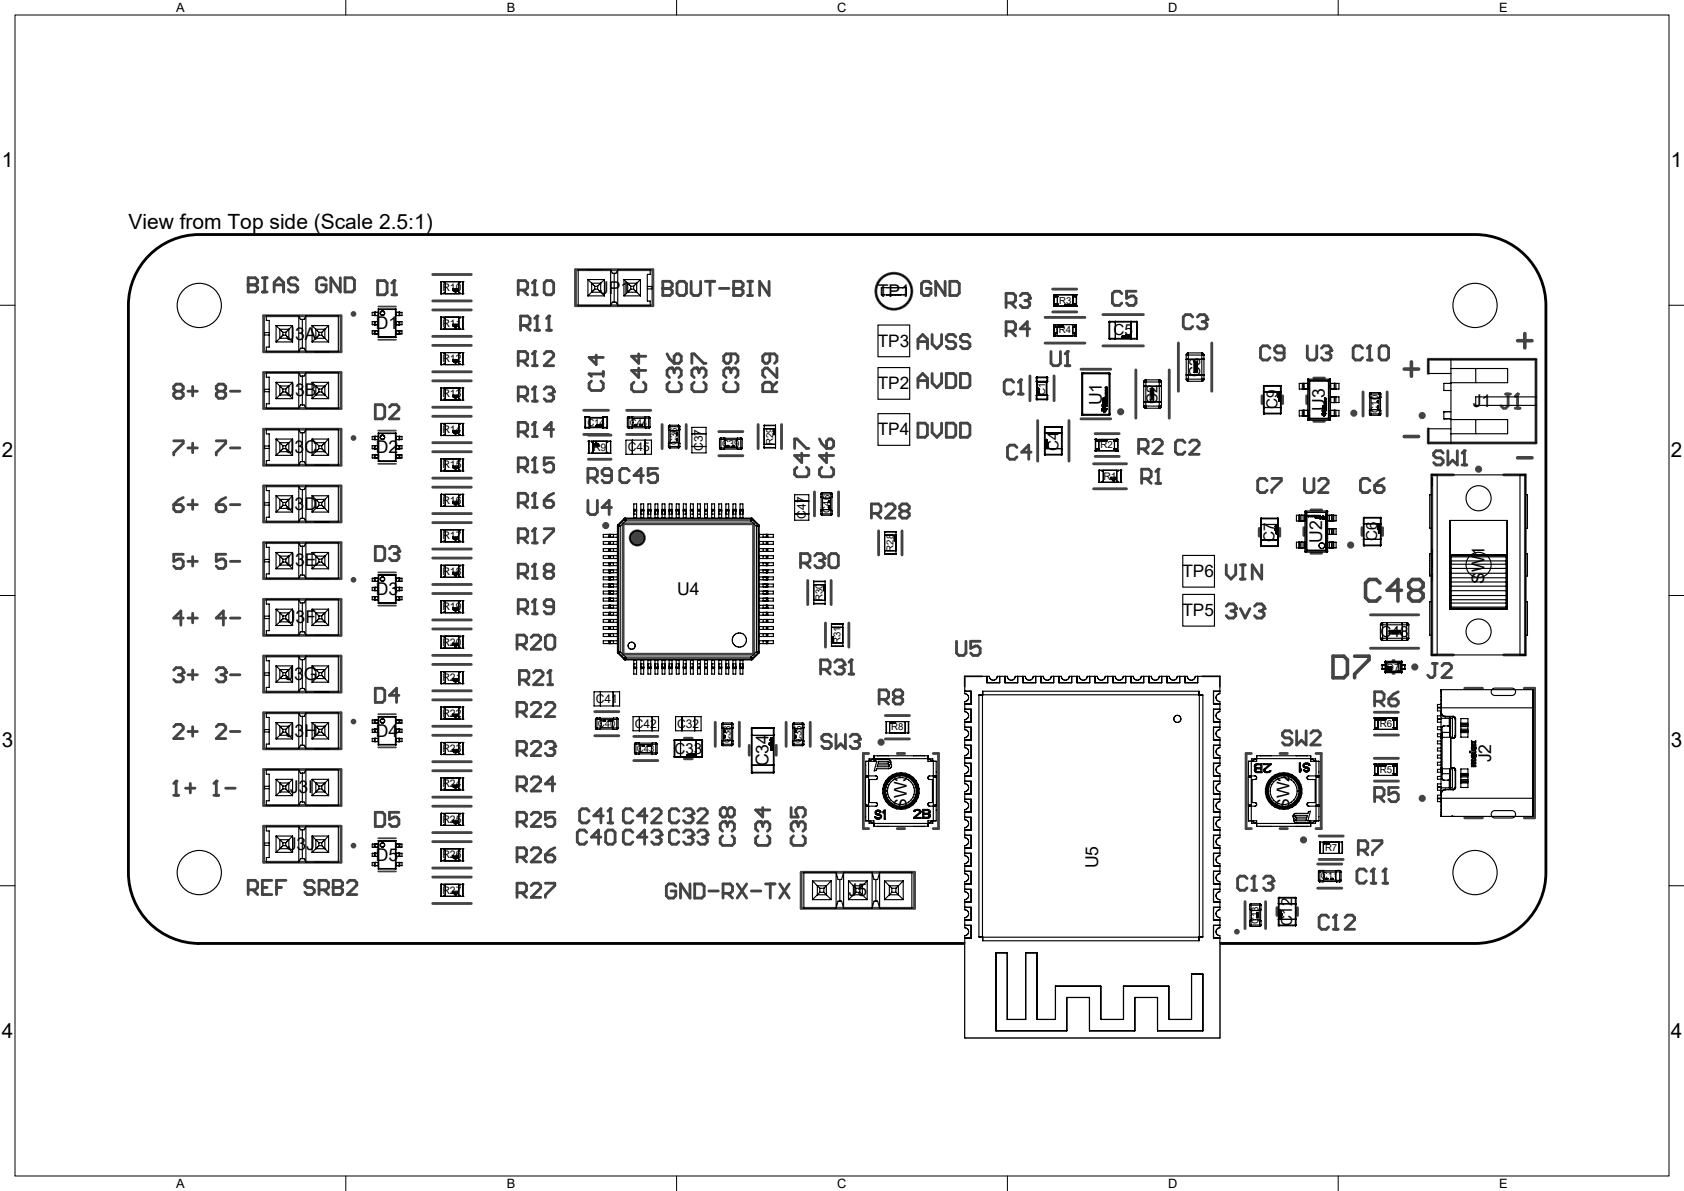
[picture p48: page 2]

View from Top side (Scale 2.5:1)

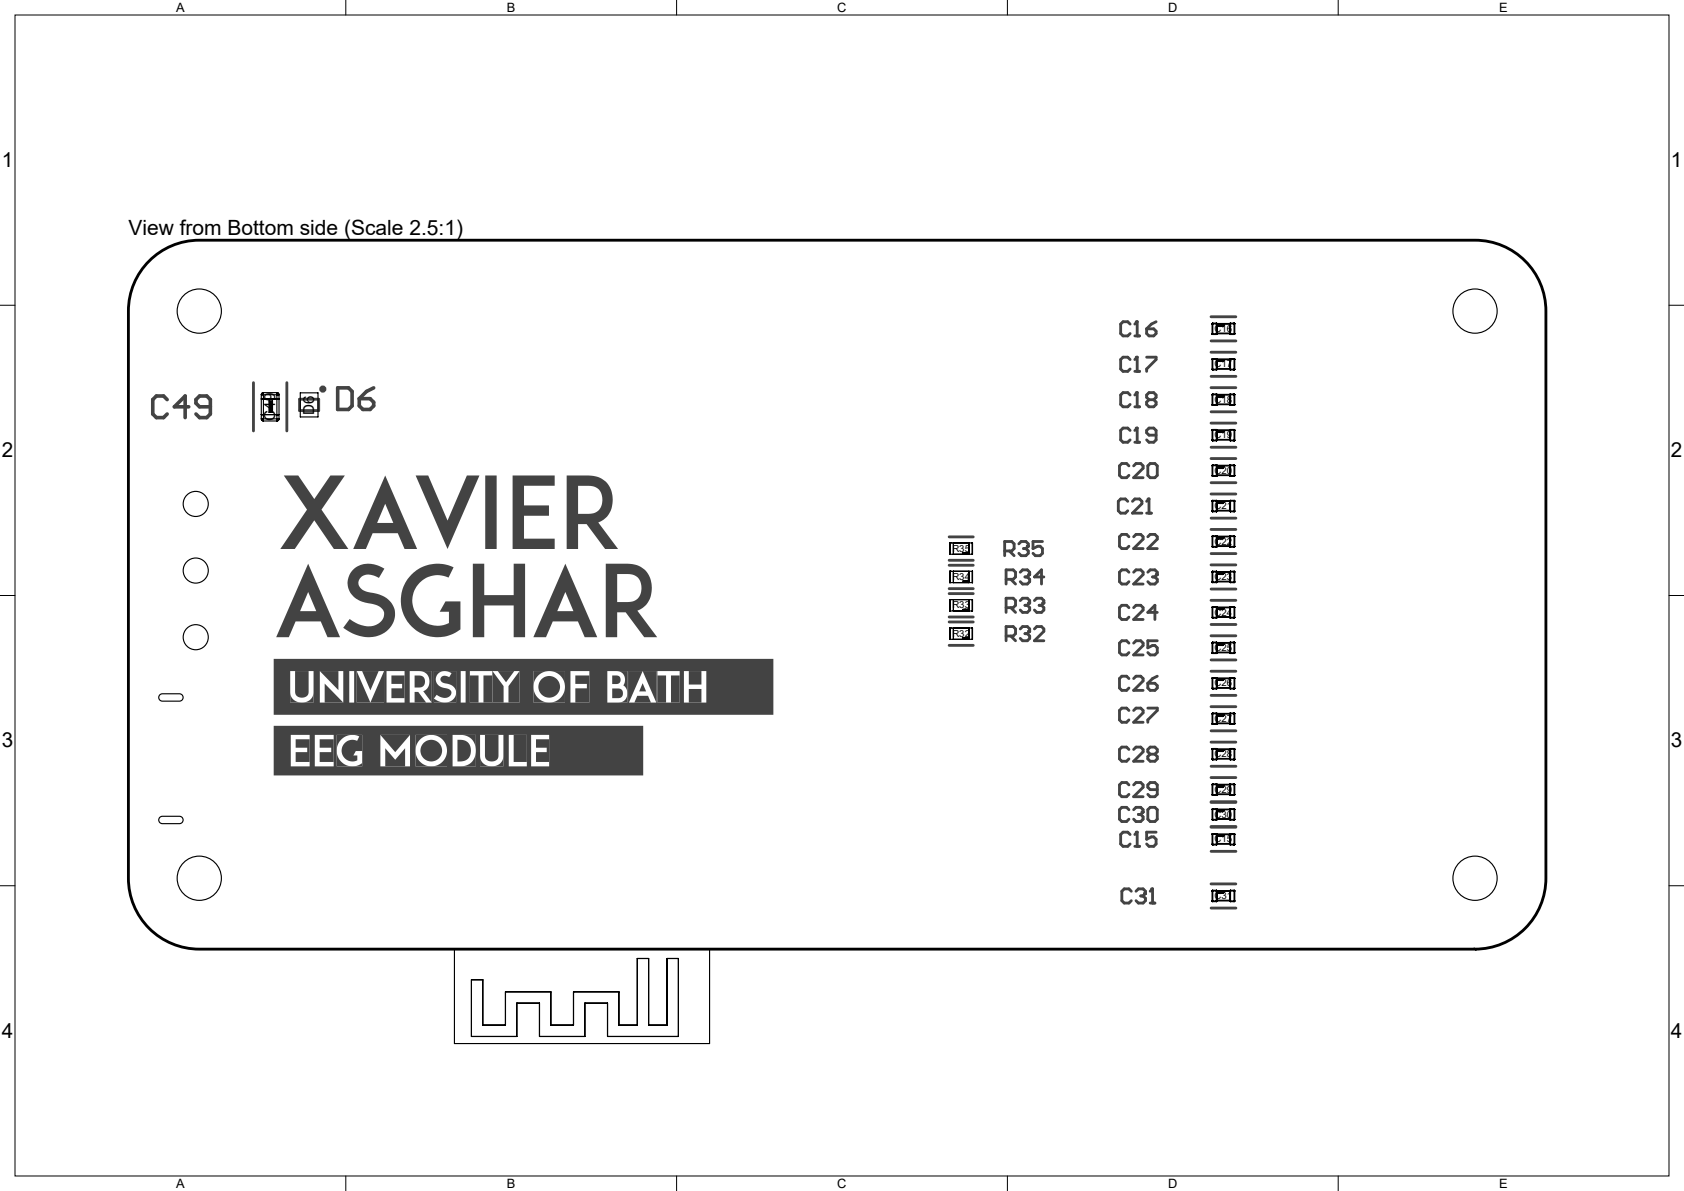
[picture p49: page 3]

View from Bottom side (Scale 2.5:1)








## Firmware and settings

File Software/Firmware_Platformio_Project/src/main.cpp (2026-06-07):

#include <Arduino.h>
#include <ADS1299.h>
#include <BLEDevice.h>
#include <BLEServer.h>
#include <BLEUtils.h>
#include <BLE2902.h>
#include <esp_gap_ble_api.h>

ADS1299 ADS;

// ADS1299 DEFINITIONS
#define RESET_PIN  14
#define DRDY_PIN   9
#define CS_PIN     10
#define MOSI_PIN   11   // AKA Data. Connected to ADS1299 DIN
#define SCK_PIN    12
#define MISO_PIN   13   // AKA Quad. Connected to ADS1299 DOUT
#define START_PIN  18

// BLUETOOTH DEFINITIONS
#define bleServerName "ESP32_EEG_DATA"                              //BLE server name
#define SERVICE_UUID "91bad492-b950-4226-aa2b-4ede9fa42f59"         //BLE service UUID (randomly generated)
#define CHARACTERISTIC_UUID "cba1d466-344c-4be3-ab3f-189f80dd7518"  //BLE characteristic UUID (randomly generated)
BLECharacteristic *pCharacteristic = NULL;

// FUNCTION DECLARATIONS
void IRAM_ATTR dataReadyISR();              // DRDY Interrupt
void IRAM_ATTR buttonISR();                 // Button Interrupt
void myGapHandler(esp_gap_ble_cb_event_t event, esp_ble_gap_cb_param_t *param); // GAP event handler for debugging
void readADSDataTask(void * pvParameters);  // Core 1: Read Data from ADS1299
void sendDataTask(void * pvParameters);     // Core 0: Send Data to PC

// VARIABLES
SemaphoreHandle_t drdySemaphore;            // Semaphore to signal when DRDY goes low 
QueueHandle_t packetQueue;                  // Create a queue to pass 33-byte arrays between cores
uint8_t sampleCounter = 0;
volatile bool deviceConnected = false;      // Flag to track BLE connection status

// HARDWARE BUTTON DEFINITION
#define BOOT_BUTTON_PIN 0
volatile bool triggerRecordMode = false; // Flag to trigger state change

// --------------------------------------------------------------------------------------------------------------------------------------

//Setup bluetooth callbacks onConnect and onDisconnect
class MyServerCallbacks: public BLEServerCallbacks {
  void onConnect(BLEServer* pServer, esp_ble_gatts_cb_param_t *param) {
    deviceConnected = true;
    Serial.println("Device connected!");
    pServer->updateConnParams(param->connect.remote_bda, 6, 12, 0, 400);  // Can change 12 to 10 to force a faster intervaL.
    esp_ble_gap_set_pkt_data_len(param->connect.remote_bda, 251); // Request data length extension
  };

  void onDisconnect(BLEServer* pServer) {
    deviceConnected = false;
    Serial.println("Device disconnected. Restarting advertising...");
    // Restart advertising to allow reconnection
    pServer->getAdvertising()->start();
  }
};

// --------------------------------------------------------------------------------------------------------------------------------------

void setup() {
  Serial.begin(115200);
  delay(1000);
  Serial.printf("PSRAM size: %u bytes\n", ESP.getPsramSize());

  // Boot button setup
  pinMode(BOOT_BUTTON_PIN, INPUT_PULLUP);
  attachInterrupt(digitalPinToInterrupt(BOOT_BUTTON_PIN), buttonISR, FALLING);

  // Initialize Queue holding up to 256 packets of 28 bytes
  packetQueue = xQueueCreate(256, 28 * sizeof(uint8_t));

  // BLUETOOTH LOW ENERGY SETUP
  BLEDevice::init(bleServerName);                               // Create the BLE Device
  BLEDevice::setMTU(512);                                       // Set MTU to maximum to allow for larger packets and reduce fragmentation
  BLEServer *pServer = BLEDevice::createServer();               // Set BLE device as a server
  pServer->setCallbacks(new MyServerCallbacks());               // Assign callback function
  BLEService *pService = pServer->createService(SERVICE_UUID);  // Start BLE service with service UUID
  pCharacteristic = pService->createCharacteristic(CHARACTERISTIC_UUID,BLECharacteristic::PROPERTY_NOTIFY);   // Create a BLE Characteristic with notify property
  pCharacteristic->addDescriptor(new BLE2902());                // Add a BLE2902 descriptor to allow notifications
  pService->start();                                            // Start the service
  BLEAdvertising *pAdvertising = BLEDevice::getAdvertising();   // Start advertising
  pAdvertising->addServiceUUID(SERVICE_UUID);
  pServer->getAdvertising()->start();
  BLEDevice::setCustomGapHandler(myGapHandler);
  delay(1000);

  // SETUP ADS1299
  ADS.setup(DRDY_PIN, CS_PIN, SCK_PIN, MISO_PIN, MOSI_PIN, RESET_PIN, START_PIN);
  digitalWrite(START_PIN, LOW);     // Pull start low to stop conversations
  delay(10);
  ADS.SDATAC();                     // Stop continuous data mode to allow register configuration
  ADS.WREG(GPIO, 0b00000000);
  ADS.WREG(CONFIG1, 0b10010101);    // Set SPS (110 = 250, 101 = 500, 100 = 1000)
  ADS.WREG(CONFIG3, 0b11111110);    // Enable power-down reference buffer, bias measurement, internal bias ref, bias buffer and bias lead off
  ADS.WREG(CONFIG4, 0b00000010);    // Enable lead-off comparator

  ADS.WREG(MISC1, 0b00100100);      // Connect SRB1 to inverting inputs.
  ADS.WREG(BIAS_SENSP, 0b00000001); // Set which positive channels to use for bias
  ADS.WREG(BIAS_SENSN, 0b00000000); // Set which negative channels to use for bias

  ADS.WREG(LOFF, 0b00000100);
  ADS.WREG(LOFF_SENSP, 0b11111111); // Enable lead-off detection for channel 1p)
  ADS.WREG(LOFF_SENSN, 0b00000001); // Enable lead-off detection for channel 1n)

  for(int i=CH1SET; i<=CH8SET; i++) ADS.WREG(i, 0b01100000);
 
  drdySemaphore = xSemaphoreCreateBinary();                                 // Create a binary semaphore to signal when DRDY goes low
  attachInterrupt(digitalPinToInterrupt(DRDY_PIN), dataReadyISR, FALLING);  // Set up DRDY interrupt on falling edge
  ADS.RDATAC();                     // Start continuous data mode
  digitalWrite(START_PIN, HIGH);    // Pull start high to begin conversations
  delay(10);

  // Core 1: Read Data from ADS1299
  xTaskCreatePinnedToCore(
    readADSDataTask,   
    "ReadTask",        
    4096,              
    NULL,              
    3,        
    NULL,              
    1);

  // Core 0: Send Data to PC
  xTaskCreatePinnedToCore(
    sendDataTask,      
    "SendTask",        
    4096,              
    NULL,              
    1,                 
    NULL,              
    0);

  Serial.println("Setup complete\n");
}

// --------------------------------------------------------------------------------------------------------------------------------------

void loop() {
  // If the BOOT button is pressed, turn off lead off
  if (triggerRecordMode) {
    triggerRecordMode = false; // Reset flag

    // Stop conversations and stop continuous data mode
    digitalWrite(START_PIN, LOW);
    delay(10);
    ADS.SDATAC();
    
    // 2. Check bias lead-off
    uint8_t config3_val = ADS.RREG(CONFIG3); 
    bool biasDisconnected = (config3_val & 0b00000001);
    if (biasDisconnected) {
      Serial.println("Bias Disconnected");
    } else {
      Serial.println("Bias Connected");
    }

    // Turn off lead off detection
    ADS.WREG(LOFF_SENSP, 0b00000000); 
    ADS.WREG(LOFF_SENSN, 0b00000000);
    ADS.WREG(CONFIG3, 0b11111100);
    
    // Restart continuous data mode
    ADS.RDATAC();
    digitalWrite(START_PIN, HIGH);
    delay(10);
    
    Serial.println("Lead-off disabled\n");
    vTaskDelete(NULL);
  }

  // Delay to yeild to other tasks
  delay(100);
}

// --------------------------------------------------------------------------------------------------------------------------------------

void IRAM_ATTR buttonISR() {
  triggerRecordMode = true;
}

// --------------------------------------------------------------------------------------------------------------------------------------

void IRAM_ATTR dataReadyISR() {
  BaseType_t xHigherPriorityTaskWoken = pdFALSE;
  // Give the semaphore
  xSemaphoreGiveFromISR(drdySemaphore, &xHigherPriorityTaskWoken);
  
  // Force a context switch if the read task is ready
  if (xHigherPriorityTaskWoken) {
    portYIELD_FROM_ISR();
  }
}

// --------------------------------------------------------------------------------------------------------------------------------------

void myGapHandler(esp_gap_ble_cb_event_t event, esp_ble_gap_cb_param_t *param) {
    if (event == ESP_GAP_BLE_SET_PKT_LENGTH_COMPLETE_EVT) {
        Serial.printf("DLE: status=%d tx=%d rx=%d\n",
            param->pkt_data_lenth_cmpl.status,
            param->pkt_data_lenth_cmpl.params.tx_len,
            param->pkt_data_lenth_cmpl.params.rx_len);
    }
    
    if (event == ESP_GAP_BLE_UPDATE_CONN_PARAMS_EVT) {
    Serial.printf("Conn params: interval=%d (%.2f ms), latency=%d, timeout=%d ms\n",
        param->update_conn_params.conn_int,
        param->update_conn_params.conn_int * 1.25,
        param->update_conn_params.latency,
        param->update_conn_params.timeout * 10);
}
}

// --------------------------------------------------------------------------------------------------------------------------------------

void readADSDataTask(void * pvParameters) {
  uint8_t dataPacket[28];
  
  for(;;) {
    // Sleep until ISR gives semaaphore
    if (xSemaphoreTake(drdySemaphore, portMAX_DELAY) == pdTRUE) {
      
      // Assign Sample Counter
      dataPacket[0] = sampleCounter++;

      // Read SPI Data
      ADS.updateDataPacket(dataPacket);

      // Send to the Bluetooth Core
      xQueueSend(packetQueue, dataPacket, 0); 
    }
  }
}

// --------------------------------------------------------------------------------------------------------------------------------------

void sendDataTask(void * pvParameters) {
  uint8_t singlePacket[28]; // Holds one packet of 28 bytes received from the queue
  uint8_t batchBuffer[224]; // Holds 8 packets of 28 bytes
  int batchCount = 0;
  
  for(;;) {
    // Clear queue and reset batch if no device is connected
    if (!deviceConnected) {
      xQueueReset(packetQueue);
      batchCount = 0;
      vTaskDelay(pdMS_TO_TICKS(100));  // sleep while disconnected
      continue;
    }

    // Wait for a single 28-byte packet from Core 1
    if (xQueueReceive(packetQueue, &singlePacket, portMAX_DELAY) == pdPASS) {
      
      // Copy the 28 bytes into the correct slot of 224-byte batch buffer
      memcpy(&batchBuffer[batchCount * 28], singlePacket, 28);
      batchCount++;

      // After 8 packets, send the full 224-byte batch
      if (batchCount == 8) {
        pCharacteristic->setValue(batchBuffer, 224);
        pCharacteristic->notify();
        
        batchCount = 0;
      }
    }
  }
}

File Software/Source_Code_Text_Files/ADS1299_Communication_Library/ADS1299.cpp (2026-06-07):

/*
ADS1299 Library for ESP32-S3
Originally created by: Conor Russomanno (https://github.com/conorrussomanno/ADS1299)
Modified by: Xavier Asghar
Modifications include:
 - Replaces ATmega328P SPI implementation with Arduino's built-in SPI library
 - Changes updateData function to be called from an ISR rather than polled from the main loop
 - updateData now returns a integer long rather than printing to the serial monitor
 - Adds updateDataPacket function that drops data directly into a numbered byte array to be sent over bluetooth
*/

# include "ADS1299.h"

SPISettings adsSPI(2000000, MSBFIRST, SPI_MODE1);

void ADS1299::setup(int _DRDY_PIN, int _CS_PIN, int _SCK_PIN, int _MISO_PIN, int _MOSI_PIN, int _RESET_PIN, int _START_PIN){
    
    tCLK = 0.489;   // (uS) Assuming default 2.048 MHz clock
    tSDECODE = 5.0; // (uS) tSDECODE > 4 tCLK (Datasheet, pg. 40)
    scaleFactorUV = 45.0 / (24.0 * 8388608.0);
    outputCount = 0;

    // Initalise pins variablkes
    DRDY_PIN = _DRDY_PIN;
    CS_PIN = _CS_PIN;
    SCK_PIN = _SCK_PIN;
    MISO_PIN = _MISO_PIN;
    MOSI_PIN = _MOSI_PIN;
    RESET_PIN = _RESET_PIN;
    START_PIN = _START_PIN;

    // Initialise pin modes
    pinMode(DRDY_PIN, INPUT);
    pinMode(START_PIN, OUTPUT);
    pinMode(CS_PIN, OUTPUT);
    pinMode(RESET_PIN, OUTPUT);

    digitalWrite(RESET_PIN, HIGH);  // Keep ADS1299 out of reset
    digitalWrite(START_PIN, HIGH);  
    digitalWrite(CS_PIN, HIGH);     // Deselect the ADS1299 initially

    // Initialise SPI
    SPI.begin(SCK_PIN, MISO_PIN, MOSI_PIN, -1);

    delay(1000);                   // tPOR > 0.128s (Datasheet, pg. 70)
    digitalWrite(RESET_PIN, LOW);  
    delayMicroseconds(2);          // tRST > 0.977us (Datasheet, pg. 70)
    digitalWrite(RESET_PIN, HIGH); 
    delay(10);                     // Wait > 18 tCLK (Datasheet, pg. 70)
    
}

//System Commands
void ADS1299::WAKEUP() {
    SPI.beginTransaction(adsSPI);
    digitalWrite(CS_PIN, LOW);      // Set CS Low to communicate
    delayMicroseconds(tSDECODE);
    SPI.transfer(_WAKEUP);
    delayMicroseconds(tSDECODE);    // Must wait 4 or more tCLK cycles before taking CS high (Datasheet, pg. 38)
    digitalWrite(CS_PIN, HIGH);     // Set CS High to end communication
    SPI.endTransaction();
    delayMicroseconds(tSDECODE);        
}

void ADS1299::STANDBY() {
    SPI.beginTransaction(adsSPI);
    digitalWrite(CS_PIN, LOW);      
    delayMicroseconds(tSDECODE);
    SPI.transfer(_STANDBY);
    delayMicroseconds(tSDECODE);    
    digitalWrite(CS_PIN, HIGH);  
    SPI.endTransaction();   
    delayMicroseconds(tSDECODE);     
}

void ADS1299::RESET() {
    SPI.beginTransaction(adsSPI);
    digitalWrite(CS_PIN, LOW);      
    delayMicroseconds(tSDECODE);
    SPI.transfer(_RESET);
    delayMicroseconds(tSDECODE);    
    digitalWrite(CS_PIN, HIGH); 
    SPI.endTransaction();    
    delayMicroseconds(10);          // At least 18 tCLK cycles required to execute RESET commmand (Datasheet, pg. 41) 
}

void ADS1299::START() {
    SPI.beginTransaction(adsSPI);
    digitalWrite(CS_PIN, LOW);      
    delayMicroseconds(tSDECODE);
    SPI.transfer(_START);
    delayMicroseconds(tSDECODE);    
    digitalWrite(CS_PIN, HIGH);
    SPI.endTransaction();     
    delayMicroseconds(tSDECODE);   
}

void ADS1299::STOP() {
    SPI.beginTransaction(adsSPI);
    digitalWrite(CS_PIN, LOW);      
    delayMicroseconds(tSDECODE);
    SPI.transfer(_STOP);
    delayMicroseconds(tSDECODE);    
    digitalWrite(CS_PIN, HIGH); 
    SPI.endTransaction();    
    delayMicroseconds(tSDECODE);   
}

//Data Read Commands
void ADS1299::RDATAC() {
    SPI.beginTransaction(adsSPI);
    digitalWrite(CS_PIN, LOW);      
    delayMicroseconds(tSDECODE);
    SPI.transfer(_RDATAC);
    delayMicroseconds(tSDECODE);    
    digitalWrite(CS_PIN, HIGH);  
    SPI.endTransaction();   
    delayMicroseconds(tSDECODE);   
}

void ADS1299::SDATAC() {
    SPI.beginTransaction(adsSPI);
    digitalWrite(CS_PIN, LOW);      
    delayMicroseconds(tSDECODE);
    SPI.transfer(_SDATAC);
    delayMicroseconds(tSDECODE);    
    digitalWrite(CS_PIN, HIGH);   
    SPI.endTransaction();  
    delayMicroseconds(tSDECODE);  
}

void ADS1299::RDATA() {
    SPI.beginTransaction(adsSPI);
    digitalWrite(CS_PIN, LOW);      
    delayMicroseconds(tSDECODE);
    SPI.transfer(_RDATA);
    delayMicroseconds(tSDECODE);    
    digitalWrite(CS_PIN, HIGH);    
    SPI.endTransaction(); 
    delayMicroseconds(tSDECODE);  
}

uint8_t ADS1299::RREG(byte _address) {
    SPI.beginTransaction(adsSPI);
    digitalWrite(CS_PIN, LOW);
    delayMicroseconds(tSDECODE);

    // Byte 1: 001r rrrr, where r rrrr is the starting register address.
    SPI.transfer(_RREG | _address);
    delayMicroseconds(tSDECODE); 

    // Byte 2: 00n nnnn, where n nnnn is the number of registers to read – 1
    SPI.transfer(0x00);
    delayMicroseconds(tSDECODE); 

    // Byte 3: Send dummy byte (0x00) to keep SPI clock running.
    uint8_t regValue = SPI.transfer(0x00);
    delayMicroseconds(tSDECODE);

    digitalWrite(CS_PIN, HIGH);
    SPI.endTransaction();
    delayMicroseconds(tSDECODE);  

    // Print the result to the Serial Monitor
    Serial.print("Register Value: 0b");
    for (int i = 7; i >= 0; i--) {
      Serial.print(bitRead(regValue, i)); // Read and print each bit from left to right
    }
    Serial.println("\n");

    return regValue;
}

void ADS1299::WREG(byte _address, byte _value) {
    SPI.beginTransaction(adsSPI);
    digitalWrite(CS_PIN, LOW);
    delayMicroseconds(tSDECODE);

    // Byte 1: 010r rrrr, where r rrrr is the starting register address.
    SPI.transfer(_WREG | _address);
    delayMicroseconds(tSDECODE); 

    // Byte 2: 000n nnnn, where n nnnn is the number of registers to write – 1.
    SPI.transfer(0x00);
    delayMicroseconds(tSDECODE); 

    // Byte 3: Register data (in MSB-first format)
    SPI.transfer(_value);
    delayMicroseconds(tSDECODE);

    digitalWrite(CS_PIN, HIGH);
    SPI.endTransaction();
    delayMicroseconds(tSDECODE);  

    // Print confirmation to Serial Monitor
    Serial.print("Register 0x");
    Serial.print(_address, HEX);
    Serial.println(" modified. \n");
}
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
